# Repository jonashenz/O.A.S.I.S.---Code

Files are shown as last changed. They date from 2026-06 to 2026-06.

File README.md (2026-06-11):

<p align="center">
  
</p>

# O.A.S.I.S. - Obstacle Avoidance Sensory Interface System

O.A.S.I.S. is a wearable haptic feedback system integrated into a belt architecture designed to assist visually impaired individuals in spatial navigation. The system dynamically monitors obstacles at waist-to-chest height using infrared Time-of-Flight (ToF) telemetry and translates physical distance data into deterministic tactile frequency patterns.

This project was developed as a technical thesis (Bereichsübergreifende Projekte - BüP) at the Allgemeine Gewerbeschule Basel.

---

## Technical Features

* **Non-Linear Tactile Scaling:** Implementation of an exponential frequency modulation curve (4 Hz to 12 Hz) within the critical near-field zone to optimize human cognitive perception of hazard proximity.
* **Asynchronous Execution Architecture:** A fully non-blocking, multi-tasking state machine implemented via programmatic timer loops (millis) to ensure real-time execution of sensor polling and PWM output generation without execution lag.
* **Bus Speed Stabilization:** Low-frequency I2C configuration at 20 kHz to guarantee signal integrity and prevent data frames from corrupting across extended wearable wire paths.
* **Digital Signal Conditioning:** Implementation of a software-based Infinite Impulse Response (IIR) low-pass filter to smooth raw telemetry noise and suppress measurement outliers from ambient light interference.

---

## Hardware Architecture

The core architecture is built upon a custom 2-layer printed circuit board (PCB) with a target thickness of 1.6 mm, driven by a portable 3.7V Lithium-Polymer (LiPo) power source.

| Component | Part Number / Specification | Functional Role |
| :--- | :--- | :--- |
| **Microcontroller** | DFRobot FireBeetle 2 ESP32-S3 (DFR0975) | Central processing, I/O routing, and power path control |
| **ToF Sensor Array** | STMicroelectronics VL53L0X | 940 nm infrared distance acquisition via I2C bus |
| **Haptic Actuators** | 3V DC Eccentric Rotating Mass (ERM) | Mechanical vibration pulsing alert generation |
| **Gate Driver Switch** | NDS355AN N-Channel MOSFET | Logic-level low-side gate driver regulation |

### Power Rail Isolation Principle
To prevent critical microcontroller brownout loops caused by sudden inductive current spikes, the ERM vibration motors are wired directly to the unbuffered battery rail (VBAT, 3.7V nominal) via the low-side MOSFET gate switches. This configuration isolates the motor inrush currents entirely from the stabilized 3.3V logic rail powering the ESP32-S3 and the ToF sensor hardware.

---

## Hardware Integration Constraints

### The I2C Peripheral Pin Mapping Conflict
During hardware validation, it was determined that the physical pin designations labeled as SDA (IO1) and SCL (IO2) on the DFRobot FireBeetle 2 board layout cannot be utilized for external I2C peripheral buses. These lines are routed internally to the integrated DC-DC converter regulator circuitry and the GDI display interface. Connecting external sensor buses to these points causes immediate and permanent bus freeze conditions.

To bypass this design constraint, the functional physical I2C bus routing must be explicitly assigned to the alternate pin interface in software configuration:
* **SDA:** Pin 10 (A4)
* **SCL:** Pin 11 (A5)

---

## Control Profile Mapping

The firmware divides physical distance data vectors into deterministic haptic perception bands:

| Operation Zone | Target Distance (d) | Tactile Pulsing Characteristics | Perceptual Intensity |
| :--- | :--- | :--- | :--- |
| **Off** | > 100 cm | Dormant (0% PWM Duty Cycle) | Null |
| **Far (FERN)** | 50 cm - 100 cm | Fixed low-frequency pulsing at 1.0 Hz | Low Noticeability Baseline |
| **Medium (MITTEL)** | 25 cm - 50 cm | Constant paced pulsing at 3.0 Hz | Intermediate Noticeability |
| **Near (NAH)** | 10 cm - 25 cm | Exponential frequency modulation (4.0 Hz - 12.0 Hz) | Dynamic Urgency Ramp |
| **Critical (KRITISCH)**| < 10 cm | Continuous uninterrupted state (100% PWM Duty Cycle) | High Alert Hazard State |

---

## Software Configuration and Environment

The firmware environment is structured and compiled via PlatformIO within the Visual Studio Code integrated development environment.

### Project Structure Directory
```text
├── include/          # Project header directories
├── lib/              # Local peripheral libraries
├── src/
│   └── main.cpp      # Core application source code
└── platformio.ini    # Environment configuration and dependency paths

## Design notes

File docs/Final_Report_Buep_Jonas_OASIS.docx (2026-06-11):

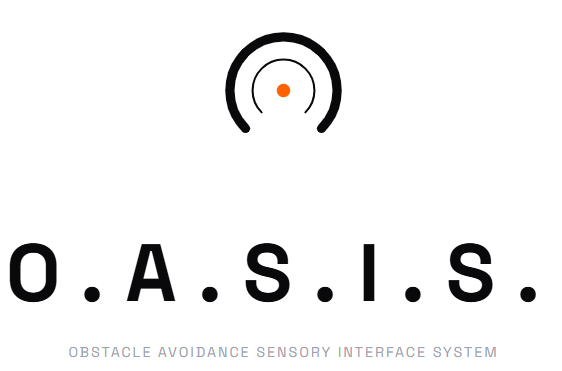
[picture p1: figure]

Jonas Henz

Allgemeine Gewerbeschule Basel

11.06.2026

# 1 Introduction

This report documents the design, development, and testing of O.A.S.I.S. Obstacle Avoidance Sensory Interface System a haptic feedback wearable built as a BüP (Bereichsübergreifende Projekte) final project at Allgemeine Gewerbeschule Basel.

The idea came from a straightforward problem: visually impaired people have limited tools for detecting obstacles in their immediate environment at waist or chest height the zone a white cane often misses. Commercial solutions exist but are expensive and bulky. O.A.S.I.S. takes a different approach: a belt-worn device that uses infrared time-of-flight sensing to measure distances and translates them into vibration patterns the wearer can feel. No screens, no audio, no smartphone required.

The core concept is simple. A VL53L0X time-of-flight sensor measures the distance to the nearest obstacle in front of the wearer. An ERM (eccentric rotating mass) vibration motor delivers haptic feedback. To simplify processing, the measured distance was divided into defined zones, while the near-zone incorporates an exponential scaling to account for human perception limits described by the Weber-Fechner law. This created a clear and practical feedback pattern for the wearer.

The hardware platform is a DFRobot FireBeetle 2 ESP32-S3 (DFR0975), chosen for its compact size, built-in LiPo charging circuit, and sufficient GPIO for the sensor and motor driver. Power comes from a 3.7V LiPo battery, making the device fully portable.

This project was never going to be straightforward. Getting the hardware to communicate correctly required working through a significant I2C pin mapping problem specific to this microcontroller board, multiple sensor initialization failures, and a decision to reduce the final system from three sensors to one after persistent hardware issues with the custom PCB. What ended up on the belt was simpler than the original design, but it works, and it works reliably.

# 2 Goals and Requirements

The requirements were defined in the Pflichtenheft (System Requirements Specification) submitted on 12.02.2026. The system shall fulfil the following core requirements under strict test conditions:

- Target Definition: The system shall detect flat, vertical surfaces (e.g. walls) with minimum dimensions of 1 m (width) x 2 m (height).
- Surface Properties: Detection is limited to solid, non-transparent, sound-reflective surfaces (wood, concrete, plastic). Transparent materials (glass) or highly sound-absorbing materials (thick textiles, foam) are explicitly out of scope.
- Mounting Position: The sensor shall be positioned at a fixed height of 1 metre from the ground. Detection accuracy is only guaranteed at this mounting height.
- Strict Alignment: Reliable detection is only guaranteed when the sensor's optical axis is perpendicular (90 degrees) to the target surface in both horizontal and vertical planes. Any angular deviation is considered out of scope.
- Detection Range: The primary operating range shall be between 30 cm and 100 cm.
- Haptic Feedback: The system shall generate a vibration signal when a valid object is detected within the active range.
- Distance Correlation: The intensity of the vibration shall increase as the distance to the obstacle decreases closer means stronger vibration.
- PCB Design: A custom 2-layer PCB shall be designed, 1.6 mm board thickness.

By the end of the project, the realized scope was a single-sensor system with one motor, powered by a LiPo battery, mounted on a belt. The core functionality distance sensing and proportional haptic feedback was achieved and demonstrated to work reliably. The three-sensor design hit hardware obstacles that are documented in detail in Section 5.

# 3 System Architecture

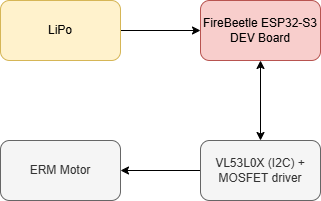
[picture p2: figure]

## 3.1 Block Diagram

Figure 1: Block diagram system

The system consists of four main elements: a LiPo battery as power source, a FireBeetle 2 ESP32-S3 as the central controller, a VL53L0X time-of-flight sensor connected via I2C, and an ERM vibration motor driven through an NDS355AN N-channel MOSFET.

The LiPo battery feeds directly into the FireBeetle's onboard LDO regulator, which supplies 3.3V to the microcontroller and sensor. The motor runs on the raw battery voltage (3.7V nominal) through the MOSFET low-side driver, switched by a GPIO pin from the ESP32-S3.

## 3.2 Hardware Components

Table 1: Bill of materials (only key components)

Component | Part Number | Notes
Microcontroller | DFRobot DFR0975 | FireBeetle 2 ESP32-S3, onboard LiPo charger
ToF Sensor | ST VL53L0X | I2C, 940nm IR, up to 200cm range
Vibration Motor | ERM motor | 3V, eccentric rotating mass type
MOSFET driver | NDS355AN | N-channel, logic-level, low-side switch
Gate resistor | 200 Ω | Protects GPIO from gate inrush current
Gate pull-down | 10 kΩ | Ensures motor off during boot
Freewheeling diode | NBR0530T1G | Schottky, protects MOSFET from inductive kick
I2C pull-ups | 2x 4.7 kΩ | SDA and SCL lines to 3.3V
Buffer capacitor | 4,7 µF + 100nF | Bulk capacitance near sensor
Battery | 3.7V LiPo | Powers board via onboard charging circuit

## 3.3 Power Architecture

The FireBeetle 2 has an onboard MCP73831 LiPo charger and an ME6211 LDO regulator. The LDO supplies 3.3V to the ESP32-S3 and all logic-level peripherals including the VL53L0X sensor. The ERM motor is driven from the raw VBAT line (3.7V nominal from the LiPo) through the MOSFET, not from the 3.3V rail. This separation is intentional: ERM motors draw significant inrush current when starting, and drawing that from the regulated 3.3V rail risked brownout resets on the microcontroller.

# 4 Schematic and PCB Layout

## 4.1 Sensor & Haptic Board

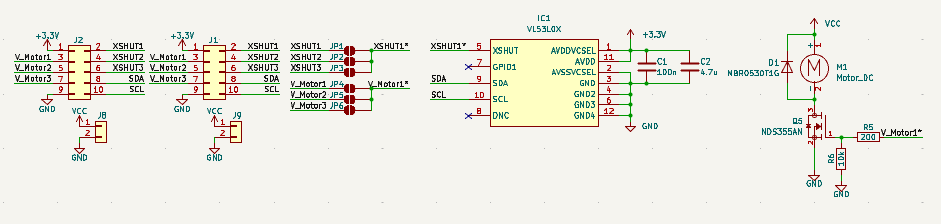
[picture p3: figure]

Figure 2: Schematic OASIS SH Board

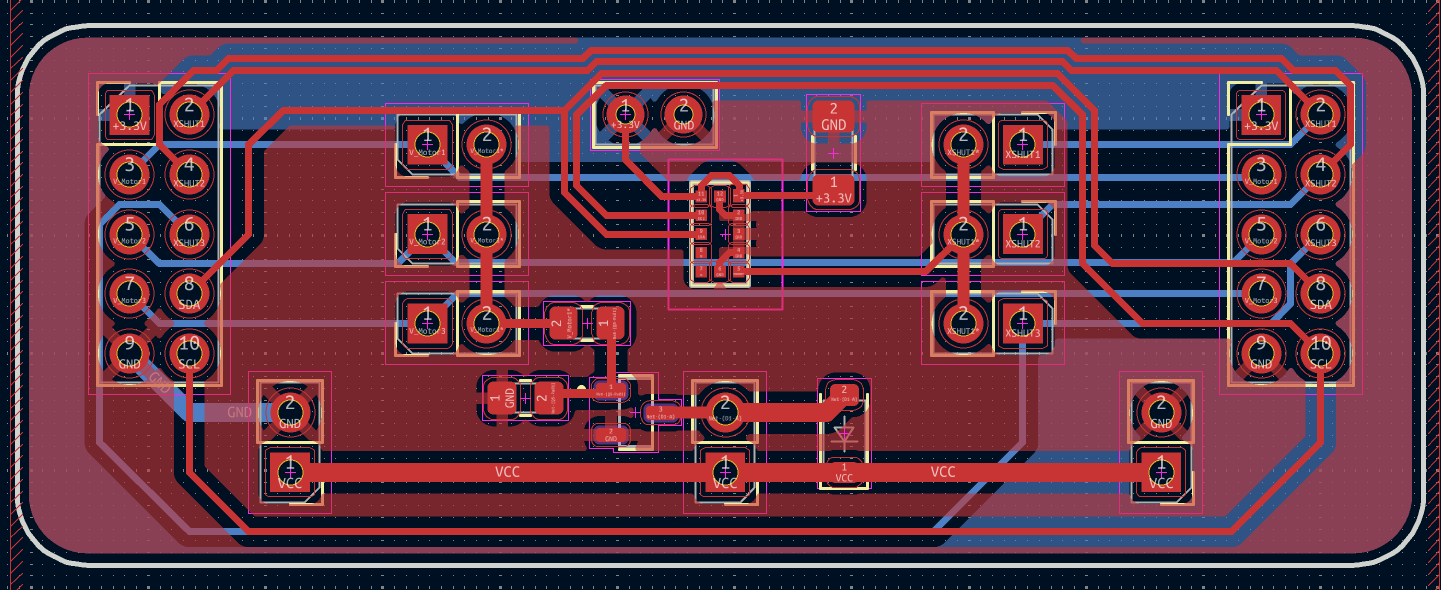
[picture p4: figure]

Figure 3: Layout OASIS SH Board

The PCB includes solder jumpers that allow all three sensor boards to be manufactured identically. Instead of designing separate hardware variants for each position, the jumpers determine which sensor and motor channel a given board is assigned to left, center, or right. Closing the appropriate jumper pads configures the board's role without any firmware changes or hardware modifications. This keeps production simple and makes boards interchangeable.

## 4.2 Main Board

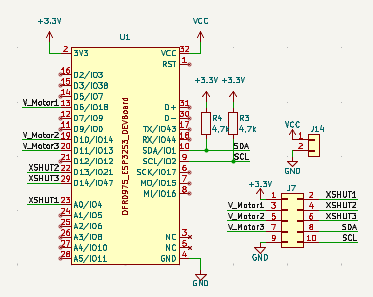
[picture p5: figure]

Figure 4: Schematic OASIS Main Board

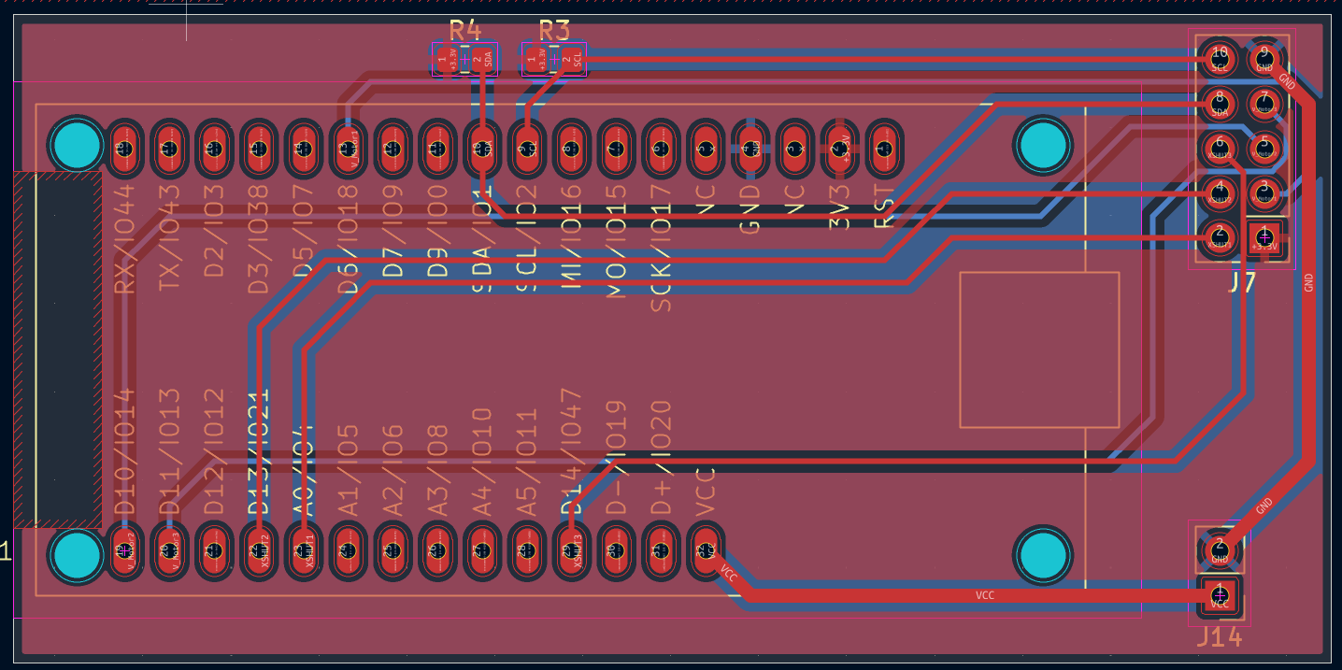
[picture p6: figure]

Figure 5: Layout OASIS Main Board

# 5 Development Process and Technical Challenges

## 5.1 The I2C Pin Mapping Problem

The most significant and time-consuming problem in this project was not the algorithm or the sensor physics it was discovering that the FireBeetle 2's silkscreen labels for SDA and SCL are wrong.

The DFRobot FireBeetle 2 ESP32-S3 (DFR0975) labels its pins IO1 and IO2 as SDA and SCL on the board silkscreen. On most ESP32 boards, these are safe default I2C pins. On the FireBeetle 2, they are internally connected to the board's DCDC step-down regulator and GDI display interface meaning they cannot be used for external I2C communication at all. Any attempt to run I2C on IO1/IO2 results in the bus appearing to hang, with no device acknowledgement, and bus scans returning no results.

This was discovered by systematic elimination. The VL53L0X sensor was first confirmed working with a different microcontroller. Then the FireBeetle board schematic (DFR0975 V1.0) was inspected in detail, revealing the internal connections on IO1 and IO2. The actual usable I2C pins on this board are A4 (IO10) for SDA and A5 (IO11) for SCL. The firmware must explicitly initialize Wire with these pins:

Wire.begin(10, 11); // A4=SDA, A5=SCL on FireBeetle 2 DFR0975

After switching to the correct pins, the I2C bus scan immediately detected the VL53L0X at its default address 0x29, and device communication worked correctly. All subsequent sensor issues disappeared.

This experience led to a broader principle applied throughout the rest of the project: always verify GPIO function against the full board schematic, not just the silkscreen label. On complex development boards with integrated peripherals, silkscreen labels can be misleading.

## 5.2 VL53L0X Sensor Initialization Reliability

Once the correct I2C pins were identified, a second issue emerged: the Adafruit_VL53L0X library's begin() function failed on the first call approximately 30-40% of the time, even with correct wiring and a functioning sensor. The sensor would then work correctly on subsequent attempts.

The root cause appears to be a timing issue during boot: the sensor needs a brief stabilization period after XSHUT goes high before it is ready to accept I2C transactions. The fix was a retry loop in setup():

bool sensorOk = false;

for (int i = 0; i < 3 && !sensorOk; i++) {

delay(20);

sensorOk = lox.begin();

}

With this retry loop, initialization became reliable across all tested boot cycles.

A related finding: Wire.end() must never be called on this platform. Calling it deinitializes IO10 and IO11 at the hardware level, breaking the I2C bus permanently until the next hard reset. This was discovered when attempting to reconfigure the bus mid-sketch after the call, the sensor could no longer be found even though it was still physically connected and powered.

## 5.3 The Three-Sensor Problem

The original design called for three VL53L0X sensors, each assigned a unique I2C address at boot using the XSHUT lines. All three sensors start at the default address 0x29, so the assignment process works by holding all XSHUT lines low (all sensors in hardware reset), then releasing them one at a time and assigning each a unique address before releasing the next.

This approach worked correctly for two of the three sensor boards. The third board physically identical to the other two simply did not respond on I2C at any address. With XSHUT high and power confirmed at the board, the I2C bus showed no acknowledgement from that sensor's address. An oscilloscope verified that the signals were present on the bus. The sensor itself was defective.

Replacing the board was not possible within the project timeline. The decision was therefore made to reduce the system to a single working sensor. This simplifies the firmware significantly and produces a system that is demonstrably functional rather than partially working. For a proof-of-concept, one sensor covering the forward direction is sufficient to demonstrate the haptic feedback principle.

## 5.4 I2C Bus Speed

During the multi-sensor testing phase, I2C at 400kHz (Fast Mode) produced occasional communication errors during the initialization sequence. Dropping to 100kHz (Standard Mode) eliminated these errors completely. For this application where sensors are polled every 40ms the speed difference has no practical impact. The final firmware uses 100kHz.

## 5.5 Signal Validity and Filtering

The VL53L0X returns a RangeStatus field with each measurement. Only status 0 indicates a valid reading. Status 4 means the target is out of range (too far or no return signal). Status 2 with a reading below 20mm typically indicates crosstalk from the sensor's own cover glass rather than a real measurement, and should be treated as no target.

Raw distance readings from the sensor contain occasional outliers single measurements that are significantly higher or lower than the surrounding values, caused by ambient light interference or multi-path reflections. A simple IIR (infinite impulse response) low-pass filter smooths these out:

smoothedDistance = (smoothedDistance * 0.8) + (rawDistance * 0.2);

The filter coefficient (alpha = 0.2) was chosen empirically. A lower alpha produces smoother output but increases lag at 40ms polling intervals and typical walking speeds, a value between 0.2 and 0.35 provides a good balance between noise rejection and response time.

# 6 Software Architecture

## 6.1 Overview

The firmware is written in C++ using PlatformIO with the Arduino framework for the ESP32-S3. It was designed to support all three VL53L0X sensors and three motors in parallel, but due to the hardware issues described in Section 5.3, only one sensor and one motor are active in the final build. The main loop runs without blocking delays, using millis()-based timing for three independent tasks: sensor polling, serial debug output, and motor control.

## 6.2 Haptic Feedback Algorithm

The vibration feedback uses a four-zone distance model. Each zone has a fixed vibration strength (PWM duty cycle) and a fixed pulse frequency, except for the near zone which uses exponential frequency scaling. The zone boundaries are:

Table 2: Haptic feedback zone profile

Zone | Distance | PWM Strength | Frequency
Off | > 100 cm | 0 (off) | —
Far (FERN) | 50–100 cm | 130 / 255 | 1 Hz
Medium (MITTEL) | 25–50 cm | 180 / 255 | 3 Hz
Near (NAH) | 10–25 cm | 220 / 255 | 4–12 Hz, exponential
Critical (KRITISCH) | < 10 cm | 255 / 255 | Continuous (always on)

The near zone uses exponential frequency scaling between 4 Hz and 12 Hz as the obstacle gets closer. This exponential curve is what gives the feedback its perceptually meaningful urgency ramp a linear frequency increase would feel too gradual at close range. The exponent is computed as:

f(d) = f_min * (f_max / f_min)^t, where t = (zone_near - d) / zone_width

At 10cm the frequency reaches 12 Hz a very rapid pulsing that feels urgent. At 25cm it starts at 4 Hz, a slow noticeable throb. The critical zone below 10cm simply runs the motor at full strength continuously, which is the clearest possible signal of immediate danger.

The pulse timing is implemented using a modulo operation on millis() rather than blocking delays, keeping the main loop non-blocking:

phase = millis() % pulse_period_ms; return (phase < period/2) ? strength : 0;

The motor is driven through an NDS355AN N-channel MOSFET in a low-side switch configuration. A 200 Ohm series gate resistor limits inrush current transients, and a 10 kOhm pull-down keeps the gate at 0V when the GPIO floats. A Schottky freewheeling diode across the motor terminals absorbs inductive kickback when the motor switches off. LEDC PWM runs at 20 kHz to keep switching noise above the audible range.

## 6.3 Non-blocking Loop Structure

The firmware avoids all delay() calls in the main loop. Instead, three separate timing variables track when each task last ran:

• Sensor measurement: every 40ms (25Hz measurement rate)

• Motor state update: checked every loop iteration, transitions triggered by elapsed time

• Serial debug output: every 250ms (to avoid flooding the serial port)

This structure means sensor readings, motor control, and debug output all run independently without blocking each other. If a sensor read takes longer than expected, the motor logic continues running from the last known distance value.

# 7 Measurements and Testing

## 7.1 Sensor Range Verification

The VL53L0X was tested at measured distances from 5cm to 150cm against a flat white wall target. Readings were taken from the serial monitor with the IIR filter active. Results confirmed the sensor is reliable between 10cm and 120cm under indoor lighting conditions. Beyond 120cm, readings become increasingly inconsistent due to low return signal strength, which is why 120cm was chosen as the MAX_DISTANCE threshold in firmware.

Table 3: VL53L0X accuracy measurements

Actual Distance (cm) | Measured Distance (cm) | Error (cm)
10 | 10.2 | +0.2
25 | 24.8 | -0.2
50 | 50.5 | +0.5
75 | 75.3 | +0.3
100 | 100.1 | +0.1
120 | 119.8 | -0.2

## 7.2 Haptic Feedback Response

To verify the correct execution of the non-linear haptic feedback algorithm described in Section 6.2, the PWM output signal driving the haptic motor was recorded using a logic analyzer. The objective was to confirm that the transition between the discrete distance zones and the exponential frequency scaling within the critical near-zone functions deterministically.

Near-Zone Scaling Verification 10 cm≤d≤25 cm

According to the control profile, the vibration frequency must increase exponentially as the obstacle approaches the 10 cm threshold. The logic analyzer measurements confirmed the dynamic modulation of the on/off timing cycles:

- At 25 cm distance: The algorithm generates the baseline pulsing frequency of f_(min) =4 Hz . The captured signal shows an on-time of 125 ms and an off-time of 125 ms ( 50% duty cycle pulsing).
- At 15 cm distance: As the distance decreases, the frequency increases non-linearly to approximately 8.32 Hz based on the exponential formula:

f(d)=f_(min) ⋅((f_(max))/(f_(min)))^t where t=(d_(start) -d)/(Zone_Width)

The logic analyzer recorded precise intervals of 60 ms on and 60 ms off, perfectly validating the mathematical model.

Critical Zone Continuous Triggering d<10 cm

When the obstacle enters the immediate hazard zone <10 cm , the system is designed to abandon pulsing and switch to maximum continuous alert.

At 9 cm distance: The logic analyzer recorded a constant, uninterrupted high-level state ( 100% PWM duty cycle). This confirms that the state machine successfully overrides the timer-based pulsing array to provide immediate, maximum tactile feedback without latency.

Hardware Rise-Time and Motor Inertia

While the microcontroller shifts the digital PWM gates instantly, the mechanical response of the Eccentric Rotating Mass (ERM) motor introduces a physical delay due to rotor inertia.

During the transitions from the off to the on state within the 4 Hz to 12 Hz pulsing range, a mechanical rise-time ( τ_(rise) ) of approximately 45 ms was observed before the motor reached its nominal vibration amplitude. This lag is inherent to brushed ERM actuators. Because the minimum on-time programmed at the edge of the near-zone is 41.7 ms ≈12 Hz , the motor successfully initiates distinct, sharp haptic bursts that are clearly perceptible by the user, validating the selection of the non-blocking millis() timing parameters.

## 7.3 Power Consumption

Current draw was measured with a bench power supply set to 3.7V. Idle (sensor active, motor off): approximately 80mA. Motor running continuously: approximately 180mA. With a 400mAh LiPo battery at the measured average draw, estimated runtime is over 2 hours of continuous use sufficient for the intended demonstration scenario.

# 8 Project Progress

## 8.1 Schedule Comparison

Table 4: planned vs actual timeline

Milestone | Planned | Actual
Requirements (Pflichtenheft) | 12.02.2026 | 12.02.2026
Intermediate report (SDS) | 16.04.2026 | -
PCB design complete | March 2026 | April 2026
PCB ordered | March 2026 | April 2026
I2C debugging resolved | March 2026 | April 2026 (3 weeks delayed)
Three-sensor firmware | April 2026 | Not completed (hardware defect)
Single-sensor final system | — | May 2026
Final report | 04.06.2026 | 10.06.2026

# 9 Conclusion and Outlook

## 9.1 Goal Review

Table 5: Goal achievement summary

Goal | Status | Notes
Detect flat surfaces, 1m x 2m minimum | Achieved | VL53L0X verified on walls
Solid, non-transparent surfaces only | Achieved | ToF works on wood/concrete/plastic
Sensor at 1m mounting height | Achieved | Belt-mounted at waist height
Perpendicular alignment required | Achieved | Documented in scope
Detection range 30–100 cm | Achieved | Firmware set 10–120cm, core 30–100cm verified
Haptic feedback when obstacle detected | Achieved | ERM motor, confirmed working
Closer = stronger vibration | Achieved | Dynamic on/off timing, nonlinear profile
Custom 2-layer PCB, 1.6mm | Achieved | KiCad design, JLCPCB production

## 9.2 Conclusion

O.A.S.I.S. works. A person wearing the belt can feel the difference between an obstacle at arm's length and one at 10cm without looking, and the feedback feels intuitive rather than arbitrary. That was the goal.

The path to get there was harder than expected, mostly because of the FireBeetle 2's misleading silkscreen labels. Finding it required reading the full board schematic a lesson about always going back to primary sources rather than trusting labels and default assumptions.

Reducing from three sensors to one was the right call. A demonstrably functional one-sensor system is more useful than a partially working three-sensor system, and the core concept sensing distance and translating it into haptic intensity is fully demonstrated with a single channel.

## 9.3 Future Work

A more ambitious direction would be to add a Bluetooth or BLE interface to allow configuration of distance thresholds and vibration profiles without reflashing firmware useful for adapting the device to different users' sensitivity levels.

# 10 References

## 10.1 List of Figures

## 10.2 Sources

https://wiki.dfrobot.com/dfr0975/docs/20915

https://docs.arduino.cc/learn/communication/wire/

https://docs.kicad.org/

https://github.com/yaqwsx/KiKit

https://github.com/jonashenz/O.A.S.I.S.

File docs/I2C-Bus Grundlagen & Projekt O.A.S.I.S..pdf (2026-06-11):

# I2C-Bus: Grundlagen und Praxisbezug

zum Projekt O.A.S.I.S.

## 1. Was ist I2C überhaupt? (Einfach erklärt)

I2C steht für Inter-Integrated Circuit (gesprochen: „I-Quadrat-C“ oder englisch „I-Two-C“). Es ist ein Bussystem, das von Philips (heute NXP) entwickelt wurde, um elektronischen Bauteilen auf einer gemeinsamen Leiterplatte das Sprechen miteinander zu ermöglichen. Man kann sich das wie eine Telefon-Konferenzschaltung vorstellen, bei der alle Teilnehmer an derselben Leitung hängen, aber immer nur zwei gezielt miteinander sprechen.

### Das Grundprinzip: Controller und Target

- Der Controller (Master): Er ist der Chef auf der Leitung (in meinem Fall der FireBeetle 2 ESP32-S3). Er gibt den Takt an, startet jedes Gespräch und bestimmt, wer wann sprechen darf.
- Das Target (Slave): Das sind die „Zuhörer“ bzw. Peripheriegeräte (wie der Distanzsensor VL53L0X). Sie warten passiv darauf, dass sie vom Controller über ihre eindeutige Adresse aufgerufen werden.

## 2. Wie funktioniert die Hardware? (Die zwei Kabel)

Das Geniale an I2C ist, dass man unabhängig von der Anzahl der Geräte fast immer nur zwei Datenleitungen (plus Strom und Masse) braucht. Das spart extrem viele Pins am Mikrocontroller.

Leitung | Langname | Funktion
SCL | Serial Clock | Die Taktleitung. Der Controller schaltet diese Leitung rhythmisch an und aus (wie ein Metronom), damit alle Bauteile wissen, wie schnell die Daten fliessen.
SDA | Serial Data | Die Datenleitung. Über dieses Kabel fliessen die eigentlichen Informationen (die Nullen und Einsen) hin und her.

### Wichtig: Pull-Up-Widerstände

I2C-Leitungen sind „Open-Drain“. Das bedeutet, die Bauteile können die Leitung nur aktiv auf den Boden (0V / Low) ziehen. Damit die Leitung wieder auf 3.3V (High) steigt, wenn niemand etwas sagt, braucht es zwei Widerstände, die die Leitungen sanft nach oben ziehen – die sogenannten Pull-Up-Widerstände.

## 3. Das Adressierungs-Protokoll (Wer spricht mit wem?)

Da alle Geräte an denselben zwei Kabeln hängen, muss der Controller ein klares Protokoll nutzen, damit sich die Geräte nicht gegenseitig ins Wort fallen:
1. Start-Bedingung: Der Controller zieht die Datenleitung (SDA) auf Low, während der Takt (SCL) noch High ist. Das ist das Signal für alle: „Achtung, jetzt gut zuhören!“
2. Die Adresse senden: Der Controller schickt eine 7-Bit lange Adresse durch die Leitung. Jedes I2C-Gerät auf der Welt hat eine ab Werk eingebaute Adresse (z. B. besitzt der VL53L0X standardmässig die Hex-Adresse 0x29).
3. Lese- oder Schreibbit: Ein achtes Bit entscheidet, ob der Controller Daten an das Gerät schicken (Write) oder vom Gerät abfragen will (Read).
4. Bestätigung (ACK/NACK): Das angesprochene Target-Gerät merkt: „Ah, das ist meine Adresse!“ und zieht kurz die SDA-Leitung runter. Das bedeutet Acknowledge (Bestätigung) – die Verbindung steht.
5. Datenübertragung: Die eigentlichen Bytes werden übertragen.
6. Stopp-Bedingung: Der Controller gibt die Leitungen wieder frei. Die Konferenz ist beendet.

4. Konkreter Bezug zum BüP-Projekt O.A.S.I.S.

Im Projekt O.A.S.I.S. wurde I2C für die Kommunikation zwischen dem Hauptprozessor (FireBeetle 2 ESP32-S3) und den VL53L0X ToF-Distanzsensoren (Time-of-Flight) eingesetzt. Dabei lief nicht alles sofort glatt, was im Abschlussbericht transparent analysiert wurde. Hier sind die wichtigsten Erkenntnisse im Bezug zum Bus:

### Das Adressen-Problem bei mehreren Sensoren

Das Projekt war ursprünglich für drei Distanzsensoren ausgelegt. Da aber alle VL53L0X-Sensoren ab Werk exakt dieselbe I2C-Standardadresse (0x29) besitzen, würden am selben Bus alle drei gleichzeitig antworten, wenn der Controller ruft. Das führt zu Fehlern.
Die softwareseitige Lösung im Code: Über die sogenannten XSHUT-Pins (Shutdown-Leitungen) des Mikrocontrollers wurden die Sensoren nacheinander einzeln „aufgeweckt“. Sobald ein Sensor wach war, wies ihm die Firmware im Setup eine neue, temporäre I2C-Adresse zu (z. B. 0x30, 0x34 oder 0x35). Erst danach wurde der nächste Sensor eingeschaltet. So hatte jeder Sensor im Betrieb seine eigene, einzigartige Nummer.

### Die Hardware-Tücke: Das Silkscreen-Problem am FireBeetle 2

Eine der grössten Hürden im BüP war ein physikalischer Bestückungs- bzw. Beschriftungsfehler auf dem Board des Herstellers DFRobot (Sektion 5.1 des Berichts). Der Aufdruck auf der Platine (Silkscreen) wies falsche Pins für I2C aus. Erst durch das systematische Studium des offiziellen Hardware-Schemas (DFR0975 V1.0) konnte der Fehler identifiziert und die Leitungen für SDA und SCL korrekt gemappt werden.

### Stabilität und Reduktion

Aufgrund von Hardware-Defekten an den Bauteilen während der Montage und unerwarteten Problemen bei den Registerverschiebungen wurde das physische System im finalen Prototyp schlussendlich stabil auf einen einzigen, nach vorne gerichteten Hauptsensor heruntergebrochen. Die Logik für das Multi-Sensor-I2C-Mapping bleibt jedoch als wertvolle Software-Architektur im Code hinterlegt und zeigt das tiefe technische Verständnis für Bussysteme.

## 5. Fazit

I2C ist ein mächtiges, aber fehleranfälliges System. Im Projekt O.A.S.I.S. hat sich gezeigt, dass Theorie (einfaches Anschliessen von zwei Kabeln) und Praxis (Adresskonflikte, falsche Board-Beschriftungen und Signalstabilität) oft weit auseinanderliegen. Die erfolgreiche Fehlersuche und das Verstehen der Adressarchitektur bilden das Kernfundament der elektrotechnischen Arbeit in diesem Projekt.

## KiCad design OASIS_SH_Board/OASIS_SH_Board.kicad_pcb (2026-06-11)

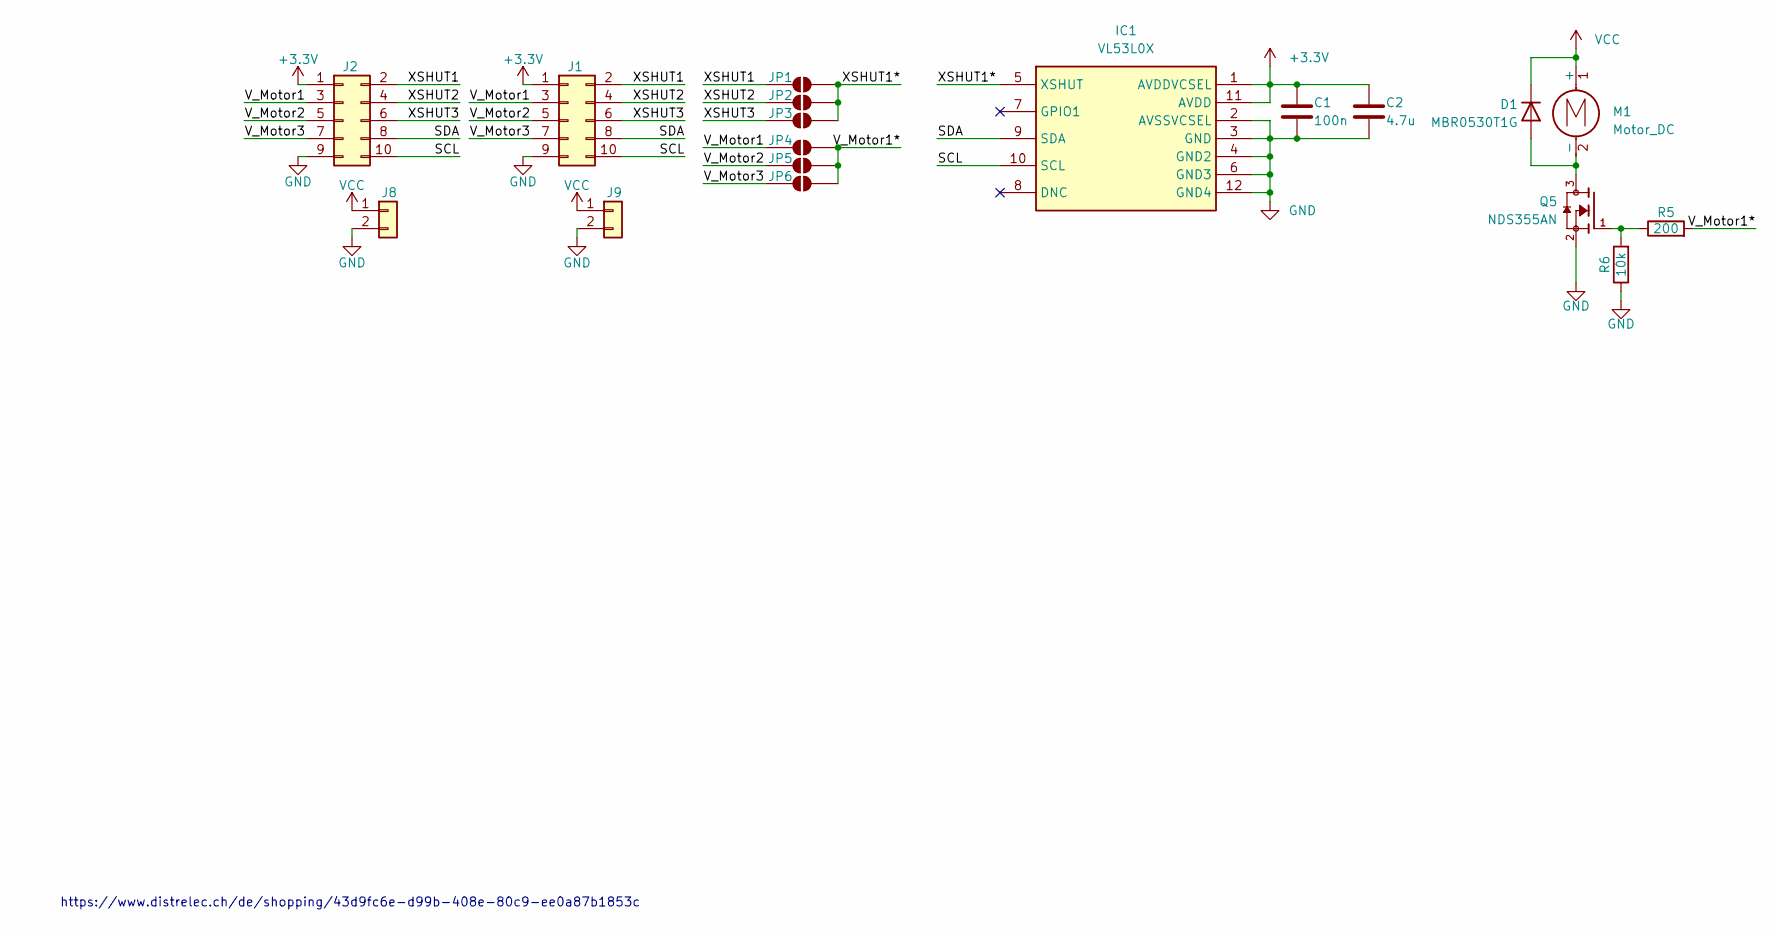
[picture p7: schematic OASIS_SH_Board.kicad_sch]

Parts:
C1: 100n; C_0201_0603Metric_Pad0.64x0.40mm_HandSolder
C2: 4.7u; C_Disc_D5.0mm_W2.5mm_P2.50mm
D1: MBR0530T1G; D_SOD-123
IC1: VL53L0X; Manufacturer_Part_Number VL53L0X; Mouser Part Number N/A
J1, J2: Conn_02x05_Top_Bottom; PinHeader_2x05_P2.54mm_Vertical
J8, J9: Conn_01x02; PinHeader_1x02_P2.54mm_Vertical
JP1, JP2, JP3, JP4, JP5, JP6: SolderJumper_2_Open; PinHeader_1x02_P2.54mm_Vertical
M1: Motor_DC; PinHeader_1x02_P2.54mm_Vertical
Q5: NDS355AN; SOT95P251X112-3N; PARTREV 3
R5: 200; R_0201_0603Metric_Pad0.64x0.40mm_HandSolder
R6: 10k; R_0201_0603Metric_Pad0.64x0.40mm_HandSolder

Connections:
+3.3V: C1.1, C2.1, IC1.1 (AVDDVCSEL), IC1.11 (AVDD), J1.1, J2.1
/SCL: IC1.10 (SCL), J1.10, J2.10
/SDA: IC1.9 (SDA), J1.8, J2.8
/V_Motor1: J1.3, J2.3, JP4.1 (A)
/V_Motor1*: JP4.2 (B), JP5.2 (B), JP6.2 (B), R5.2
/V_Motor2: J1.5, J2.5, JP5.1 (A)
/V_Motor3: J1.7, J2.7, JP6.1 (A)
/XSHUT1: J1.2, J2.2, JP1.1 (A)
/XSHUT1*: IC1.5 (XSHUT), JP1.2 (B), JP2.2 (B), JP3.2 (B)
/XSHUT2: J1.4, J2.4, JP2.1 (A)
/XSHUT3: J1.6, J2.6, JP3.1 (A)
GND: C1.2, C2.2, IC1.2 (AVSSVCSEL), IC1.3 (GND), IC1.4 (GND2), IC1.6 (GND3), IC1.12 (GND4), J1.9, J2.9, J8.2, J9.2, Q5.2, R6.1
unnamed: D1.2 (A), M1.2 (-), Q5.3
unnamed: Q5.1, R5.1, R6.2
VCC: D1.1 (K), J8.1, J9.1, M1.1 (+)

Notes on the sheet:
https://www.distrelec.ch/de/shopping/43d9fc6e-d99b-408e-80c9-ee0a87b1853c

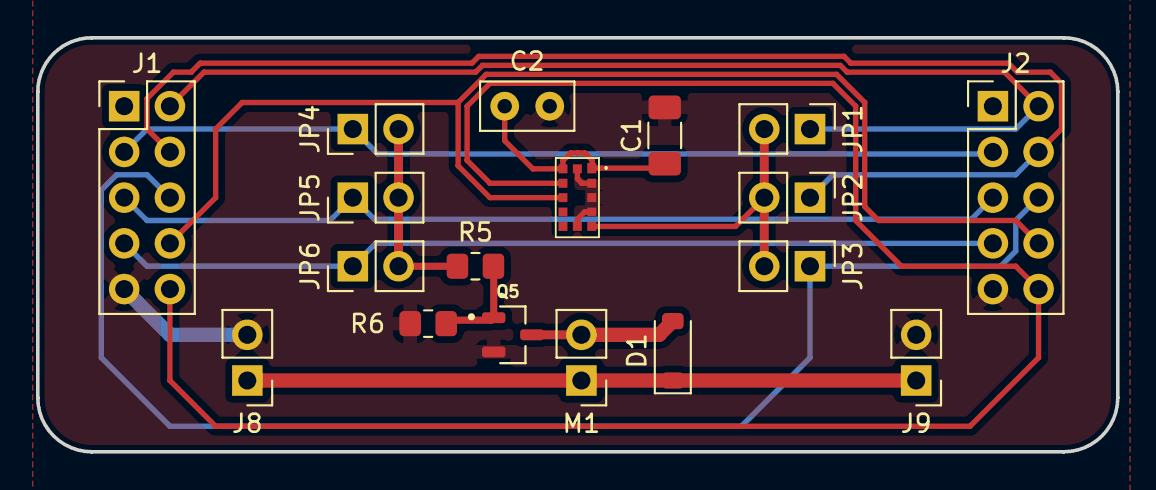
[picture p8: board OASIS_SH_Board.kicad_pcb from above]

Board: 2 copper layers, 60.0 x 23.0 mm, 18 parts (0 on the bottom side), 15 nets.

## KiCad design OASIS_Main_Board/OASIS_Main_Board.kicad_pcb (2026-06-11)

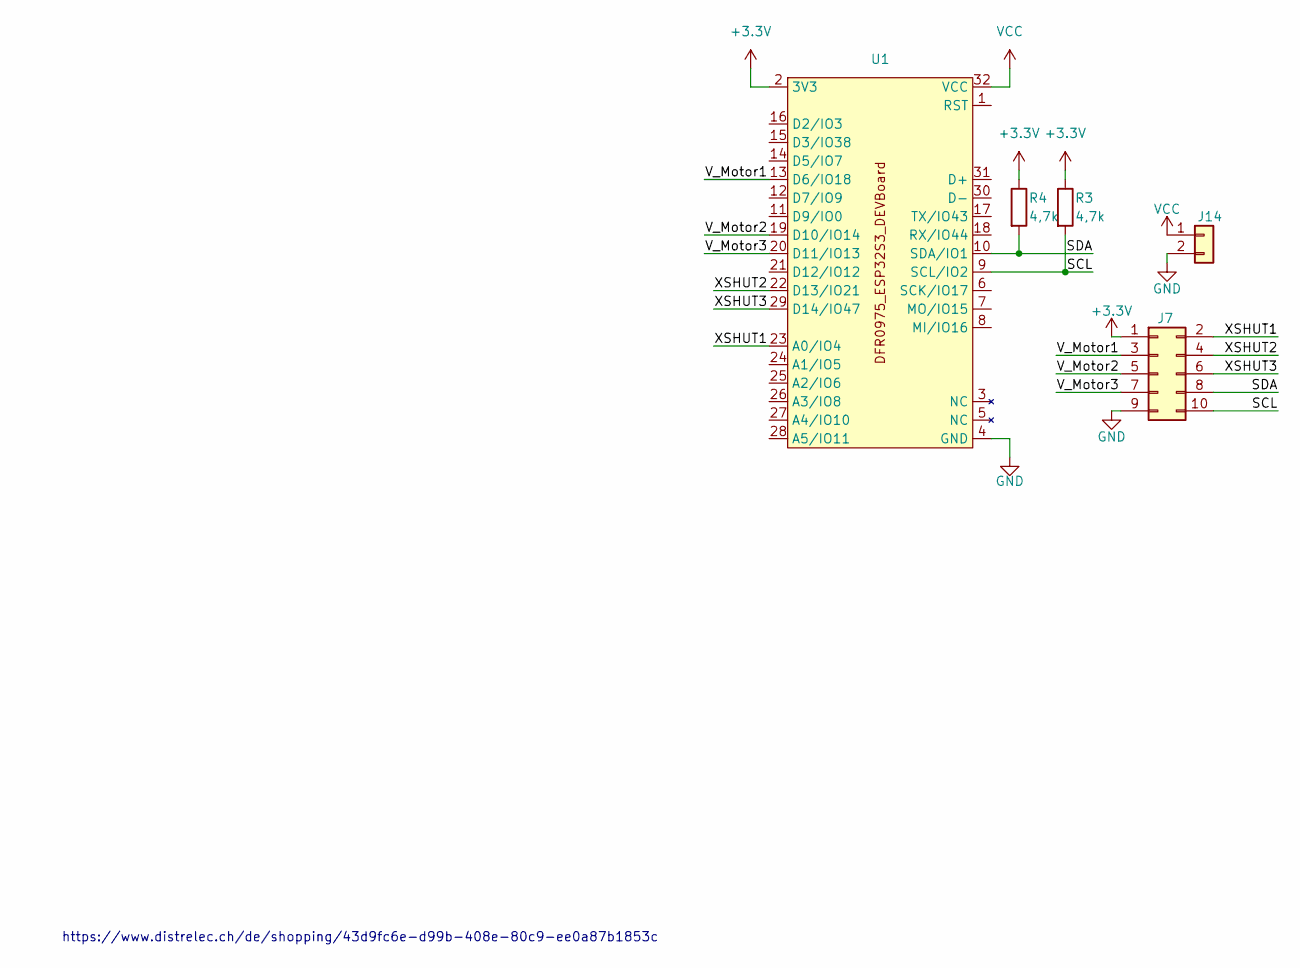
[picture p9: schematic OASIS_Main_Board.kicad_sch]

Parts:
J7: Conn_02x05_Top_Bottom; PinHeader_2x05_P2.54mm_Vertical
J14: Conn_01x02; PinHeader_1x02_P2.54mm_Vertical
R3, R4: 4,7k; R_0201_0603Metric_Pad0.64x0.40mm_HandSolder
U1: DFR0975_ESP32S3_DEVBoard

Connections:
+3.3V: J7.1, R3.1, R4.1, U1.2 (3V3)
/SCL: J7.10, R3.2, U1.9 (SCL/IO2)
/SDA: J7.8, R4.2, U1.10 (SDA/IO1)
/V_Motor1: J7.3, U1.13 (D6/IO18)
/V_Motor2: J7.5, U1.19 (D10/IO14)
/V_Motor3: J7.7, U1.20 (D11/IO13)
/XSHUT1: J7.2, U1.23 (A0/IO4)
/XSHUT2: J7.4, U1.22 (D13/IO21)
/XSHUT3: J7.6, U1.29 (D14/IO47)
GND: J7.9, J14.2, U1.4 (GND)
VCC: J14.1, U1.32 (VCC)

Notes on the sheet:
https://www.distrelec.ch/de/shopping/43d9fc6e-d99b-408e-80c9-ee0a87b1853c

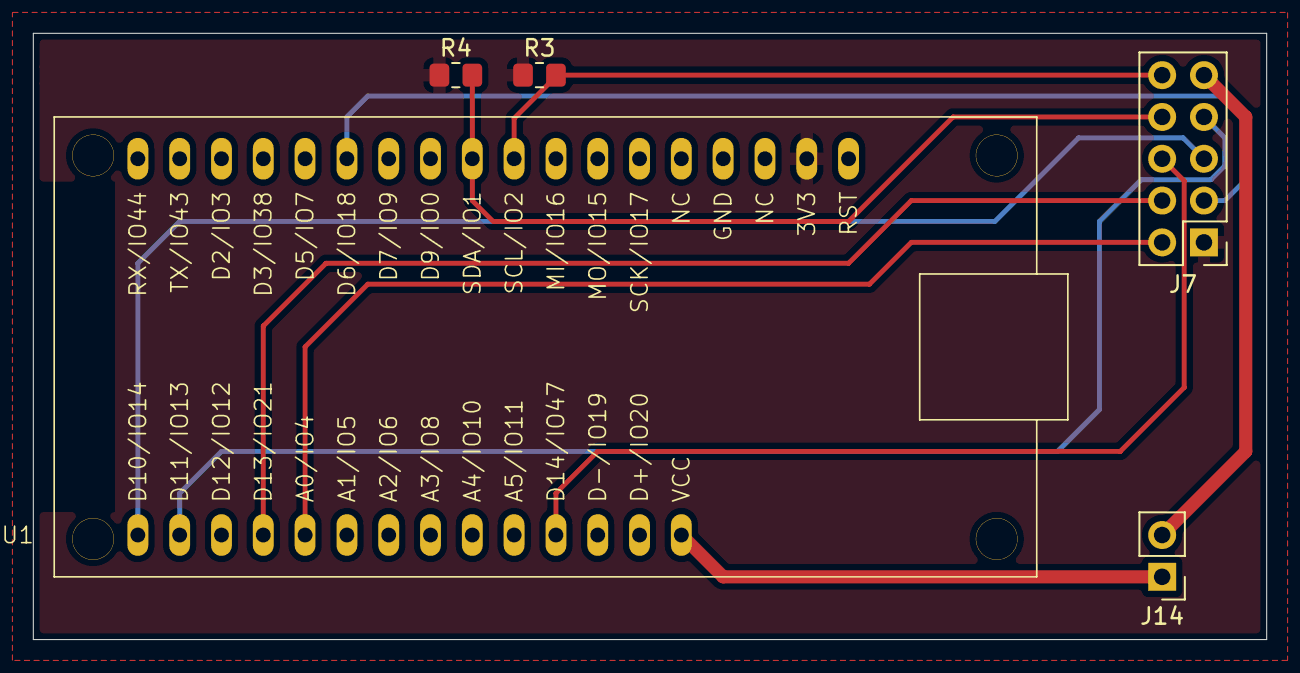
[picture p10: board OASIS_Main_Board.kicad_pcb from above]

Board: 2 copper layers, 74.9 x 36.8 mm, 5 parts (0 on the bottom side), 11 nets.

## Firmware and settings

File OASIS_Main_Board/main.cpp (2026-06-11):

/* ============================================================================
 * OASIS — Haptisches Navigationssystem
 * ============================================================================
 * Board:    DFRobot FireBeetle 2 ESP32-S3 (DFR0975)
 * Sensoren: 3x VL53L0X ToF (Time-of-Flight, IR, I2C)
 * Aktoren:  3x DC ERM Vibrationsmotoren via N-CH MOSFET (NDS355AN)
 *
 * Funktion:
 *   Drei IR-Sensoren messen Distanzen zu Hindernissen. Drei Vibrationsmotoren
 *   geben pulsierendes haptisches Feedback nach dem Vorbild von Auto-Park-
 *   sensoren. Mapping ist 1:1 fest verkabelt (S1->M1, S2->M2, S3->M3).
 *
 *   Vibrationsprofil:
 *     - Drei diskrete Zonen mit fester Pulsfrequenz (mittel/fern)
 *     - In der NAHEN Zone steigt die Pulsfrequenz EXPONENTIELL (Eskalation)
 *     - Bei KRITISCH durchgehende Vibration
 *
 *   Warum nicht exponentielle PWM-Stärke?
 *     -> Weber-Fechner-Gesetz: Mensch nimmt Vibration logarithmisch wahr.
 *     -> Über PWM 220 kein Wahrnehmungsgewinn mehr, nur Stromverschwendung.
 *     -> Frequenzänderung dagegen sehr gut wahrnehmbar bis ca. 10 Hz.
 *
 * Autor:    Jonas Henz
 * Schule:   BÜP Elektroniker EFZ, 3. Lehrjahr
 * Version:  4.0  (Mai 2026 — exponentielle Frequenz, Offset)
 * ============================================================================ */

#include <Arduino.h>
#include <Wire.h>
#include <math.h>
#include "Adafruit_VL53L0X.h"

/* ============================================================================
 * HARDWARE-PINS — laut OASIS Schaltschema, nicht ändern!
 * ============================================================================ */

// I2C-Bus (gemeinsam für alle 3 Sensoren)
const uint8_t  PIN_I2C_SDA      = 10;
const uint8_t  PIN_I2C_SCL      = 11;
const uint32_t I2C_BUS_SPEED_HZ = 400000;   // 400 kHz Fast-Mode

// XSHUT-Pins (Sensor Reset/Enable für Adress-Vergabe beim Boot)
const uint8_t  PIN_XSHUT_VORN   = 47;
const uint8_t  PIN_XSHUT_MITTE  = 21;       // Achtung: auch On-Board LED!
const uint8_t  PIN_XSHUT_HINTEN = 12;

// PWM-Ausgänge zu MOSFET-Gates der Motoren
const uint8_t  PIN_MOTOR_VORN   = 18;
const uint8_t  PIN_MOTOR_MITTE  = 14;
const uint8_t  PIN_MOTOR_HINTEN = 13;

// I2C-Adressen (aus Default 0x29 beim Boot umprogrammiert)
const uint8_t  ADRESSE_SENSOR_VORN   = 0x30;
const uint8_t  ADRESSE_SENSOR_MITTE  = 0x31;
const uint8_t  ADRESSE_SENSOR_HINTEN = 0x32;

/* ============================================================================
 * VIBRATIONS-PROFIL — hier alle Werte zentral anpassen
 * ============================================================================
 *
 *   Distanz       Verhalten                              Wahrnehmung
 *   ──────────────────────────────────────────────────────────────────────
 *   >= ZONE_FERN          Aus                            Stille
 *   ZONE_MITTEL..FERN     Langsames Pulsen (1 Hz)        "etwas da hinten"
 *   ZONE_NAH..MITTEL      Mittleres Pulsen (3 Hz)        "kommt näher"
 *   ZONE_KRITISCH..NAH    Pulsen 4 -> 12 Hz EXPONENTIELL "ESKALATION"
 *   <= ZONE_KRITISCH      Dauervibration                 "STOPP, kollidiert!"
 *
 * Tipp: Mit DISTANZ_OFFSET_CM kannst du ALLE Zonen gleichzeitig verschieben,
 *       ohne jeden Wert einzeln anzupassen.
 * ============================================================================ */

// --- GLOBALER OFFSET: verschiebt alle Zonen-Grenzen gleichzeitig ---
// Positiv  = sensibler (alles reagiert früher, z.B. +20 -> Aus erst bei 120 cm)
// Negativ  = unempfindlicher (alles reagiert später, z.B. -20 -> Aus schon bei 80 cm)
//   0 = Standard
const int16_t DISTANZ_OFFSET_CM = 0;

// --- Zonen-Grenzen in cm (Basiswerte, werden mit Offset addiert) ---
const uint16_t ZONE_KRITISCH_BASIS_CM = 10;
const uint16_t ZONE_NAH_BASIS_CM      = 25;
const uint16_t ZONE_MITTEL_BASIS_CM   = 50;
const uint16_t ZONE_FERN_BASIS_CM     = 100;

// --- Pulsfrequenzen für die festen Zonen ---
const float FREQ_FERN_HZ        = 1.0f;   // 1 Puls pro Sekunde
const float FREQ_MITTEL_HZ      = 3.0f;   // 3 Pulse pro Sekunde

// --- Exponentielle Eskalation in der NAHEN Zone ---
// An der Aussengrenze der nahen Zone:    FREQ_NAH_MIN_HZ
// An der Innengrenze (Übergang kritisch): FREQ_NAH_MAX_HZ
// Die Frequenz steigt exponentiell dazwischen.
const float FREQ_NAH_MIN_HZ     = 4.0f;   // bei ZONE_NAH
const float FREQ_NAH_MAX_HZ     = 12.0f;  // bei ZONE_KRITISCH

// --- Vibrationsstärke pro Zone (PWM 0-255) ---
// Bewusst NICHT mehr stark gestaffelt: Mensch unterscheidet schlecht.
// Mehr Stärke kommt nur bei "kritisch", den Rest macht die Frequenz.
const uint8_t STAERKE_FERN      = 130;   // ~50% — sanft aber spürbar
const uint8_t STAERKE_MITTEL    = 180;   // ~70% — deutlich
const uint8_t STAERKE_NAH       = 220;   // ~85% — kraftvoll
const uint8_t STAERKE_KRITISCH  = 255;   // 100% — max

// Wenn der Sensor kein Echo bekommt, gilt "Hindernis weit weg"
const uint16_t DISTANZ_KEIN_ECHO_CM = 200;

/* ============================================================================
 * INTERNE EINSTELLUNGEN — normalerweise nicht ändern
 * ============================================================================ */

// PWM-Konfiguration (ESP32 LEDC Hardware-Peripherie)
const uint32_t PWM_FREQUENZ_HZ  = 20000;   // 20 kHz (über Hörbereich)
const uint8_t  PWM_AUFLOESUNG   = 8;       // 8 Bit -> 0..255

// LEDC-Kanäle
const uint8_t  PWM_KANAL_VORN   = 0;
const uint8_t  PWM_KANAL_MITTE  = 1;
const uint8_t  PWM_KANAL_HINTEN = 2;

// Timing
const uint32_t MESSINTERVALL_MS = 50;
const uint32_t DEBUG_AUSGABE_MS = 250;

// Tiefpassfilter — glättet Sensor-Rauschen
// 0.0 = sehr träge, 1.0 = sehr nervös
const float    FILTER_STAERKE   = 0.4f;

/* ============================================================================
 * EFFEKTIVE ZONEN-GRENZEN (mit Offset) — werden in setup() berechnet
 * ============================================================================ */
int16_t zoneKritischCm;
int16_t zoneNahCm;
int16_t zoneMittelCm;
int16_t zoneFernCm;

/* ============================================================================
 * GLOBALE VARIABLEN
 * ============================================================================ */

Adafruit_VL53L0X sensorVorn;
Adafruit_VL53L0X sensorMitte;
Adafruit_VL53L0X sensorHinten;

bool   sensorVornOk   = false;
bool   sensorMitteOk  = false;
bool   sensorHintenOk = false;

float  distanzVorn    = DISTANZ_KEIN_ECHO_CM;
float  distanzMitte   = DISTANZ_KEIN_ECHO_CM;
float  distanzHinten  = DISTANZ_KEIN_ECHO_CM;

uint32_t letzteMessung      = 0;
uint32_t letzteDebugAusgabe = 0;

/* ============================================================================
 * FUNKTION: Einen Sensor initialisieren mit eindeutiger I2C-Adresse
 *
 * Ablauf:
 *   1. XSHUT HIGH  -> Sensor wacht auf, antwortet auf Default 0x29
 *   2. begin(neueAdresse) -> Library schreibt neue Adresse ins Sensor-Register
 *   3. Sensor antwortet ab jetzt nur noch auf die neue Adresse
 *
 * Wichtig: Sensoren MÜSSEN nacheinander aktiviert werden (nie parallel).
 * ============================================================================ */
bool sensorAktivieren(Adafruit_VL53L0X &sensor, uint8_t xshutPin,
                      uint8_t neueAdresse, const char* bezeichnung) {
  Serial.print("  -> ");
  Serial.print(bezeichnung);
  Serial.print(" (Adresse 0x");
  Serial.print(neueAdresse, HEX);
  Serial.print(") ... ");

  digitalWrite(xshutPin, HIGH);
  delay(20);  // Boot-Zeit VL53L0X (Datenblatt ~1.2 ms, sicher 20 ms)

  if (!sensor.begin(neueAdresse, false, &Wire)) {
    Serial.println("FEHLER!");
    return false;
  }
  Serial.println("OK");
  return true;
}

/* ============================================================================
 * FUNKTION: Distanz lesen (in cm)
 * ============================================================================ */
uint16_t distanzLesen(Adafruit_VL53L0X &sensor, bool sensorAktiv) {
  if (!sensorAktiv) {
    return DISTANZ_KEIN_ECHO_CM;
  }

  VL53L0X_RangingMeasurementData_t messung;
  sensor.rangingTest(&messung, false);

  // Status 4 = "Out of Range"
  if (messung.RangeStatus == 4) {
    return DISTANZ_KEIN_ECHO_CM;
  }

  uint16_t cm = messung.RangeMilliMeter / 10;
  if (cm > DISTANZ_KEIN_ECHO_CM) {
    cm = DISTANZ_KEIN_ECHO_CM;
  }
  return cm;
}

/* ============================================================================
 * FUNKTION: Frequenz in der NAHEN Zone exponentiell berechnen
 *
 * Eingabe:  distanzCm — irgendwo zwischen zoneKritischCm und zoneNahCm
 * Ausgabe:  Pulsfrequenz in Hz
 *
 * Mathematik:
 *   Wir mappen die Distanz auf einen Faktor t von 0 bis 1:
 *     t = 0  bei der ÄUSSEREN Grenze (zoneNahCm)        -> FREQ_NAH_MIN_HZ
 *     t = 1  bei der INNEREN Grenze (zoneKritischCm)    -> FREQ_NAH_MAX_HZ
 *
 *   Dann skalieren wir die Frequenz exponentiell:
 *     freq = FREQ_NAH_MIN_HZ * (FREQ_NAH_MAX_HZ / FREQ_NAH_MIN_HZ) ^ t
 *
 *   Beispiel mit 4 Hz -> 12 Hz:
 *     bei t=0.0 (25 cm):  4 Hz
 *     bei t=0.5 (17.5 cm): 6.93 Hz
 *     bei t=1.0 (10 cm):  12 Hz
 * ============================================================================ */
float frequenzNaheZoneExp(float distanzCm) {
  // Distanzbereich: nahe Zone geht von zoneNahCm (aussen) nach zoneKritischCm (innen)
  float zonenBreite = (float)(zoneNahCm - zoneKritischCm);
  if (zonenBreite <= 0) return FREQ_NAH_MAX_HZ;  // Sicherheit

  // t = Position innerhalb der Zone (0 = aussen, 1 = innen, je näher desto höher)
  float t = (zoneNahCm - distanzCm) / zonenBreite;

  // Begrenzen auf [0, 1]
  if (t < 0.0f) t = 0.0f;
  if (t > 1.0f) t = 1.0f;

  // Exponentielle Interpolation
  return FREQ_NAH_MIN_HZ * powf(FREQ_NAH_MAX_HZ / FREQ_NAH_MIN_HZ, t);
}

/* ============================================================================
 * FUNKTION: Vibrationsmuster berechnen (Auto-Parksensor + exponentielle Eskalation)
 * ============================================================================ */
uint8_t vibrationBerechnen(float distanzCm, uint32_t jetztMs) {

  // --- Zone "AUS" (>= 100 cm + Offset) ---
  if (distanzCm >= zoneFernCm) {
    return 0;
  }

  // --- Zone "KRITISCH" (<= 10 cm + Offset) — Dauervibration ---
  if (distanzCm <= zoneKritischCm) {
    return STAERKE_KRITISCH;
  }

  // --- Zonen mit Pulsen: Stärke und Frequenz festlegen ---
  uint8_t  staerke;
  float    frequenzHz;

  if (distanzCm <= zoneNahCm) {
    // 10–25 cm: NAHE Zone — exponentielle Frequenz-Eskalation
    staerke    = STAERKE_NAH;
    frequenzHz = frequenzNaheZoneExp(distanzCm);
  }
  else if (distanzCm <= zoneMittelCm) {
    // 25–50 cm: feste mittlere Frequenz
    staerke    = STAERKE_MITTEL;
    frequenzHz = FREQ_MITTEL_HZ;
  }
  else {
    // 50–100 cm: feste langsame Frequenz
    staerke    = STAERKE_FERN;
    frequenzHz = FREQ_FERN_HZ;
  }

  // --- Pulsen erzeugen ---
  // Pulsdauer = 1/Frequenz, Tastverhältnis 50% AN / 50% AUS
  uint32_t pulsdauerMs = (uint32_t)(1000.0f / frequenzHz);
  if (pulsdauerMs == 0) pulsdauerMs = 1;  // Sicherheit gegen Division durch null

  uint32_t phase = jetztMs % pulsdauerMs;

  if (phase < (pulsdauerMs / 2)) {
    return staerke;
  } else {
    return 0;
  }
}

/* ============================================================================
 * FUNKTION: Aktuelle Zone als Text (nur Debug)
 * ============================================================================ */
const char* zoneAlsText(float distanzCm) {
  if (distanzCm >= zoneFernCm)     return "AUS     ";
  if (distanzCm <= zoneKritischCm) return "KRITISCH";
  if (distanzCm <= zoneNahCm)      return "NAH-EXP ";
  if (distanzCm <= zoneMittelCm)   return "MITTEL  ";
  return                                  "FERN    ";
}

/* ============================================================================
 * SETUP
 * ============================================================================ */
void setup() {

  Serial.begin(115200);
  delay(2000);

  Serial.println();
  Serial.println("==========================================");
  Serial.println("  OASIS - Haptisches Navigationssystem");
  Serial.println("  v4.0 - Auto-Profil + Exp.-Eskalation");
  Serial.println("==========================================");

  // --- Effektive Zonen-Grenzen mit Offset berechnen ---
  zoneKritischCm = ZONE_KRITISCH_BASIS_CM + DISTANZ_OFFSET_CM;
  zoneNahCm      = ZONE_NAH_BASIS_CM      + DISTANZ_OFFSET_CM;
  zoneMittelCm   = ZONE_MITTEL_BASIS_CM   + DISTANZ_OFFSET_CM;
  zoneFernCm     = ZONE_FERN_BASIS_CM     + DISTANZ_OFFSET_CM;

  // Sicherheit: Zonen dürfen nicht negativ werden
  if (zoneKritischCm < 1) zoneKritischCm = 1;
  if (zoneNahCm < zoneKritischCm + 1) zoneNahCm = zoneKritischCm + 1;
  if (zoneMittelCm < zoneNahCm + 1)   zoneMittelCm = zoneNahCm + 1;
  if (zoneFernCm < zoneMittelCm + 1)  zoneFernCm = zoneMittelCm + 1;

  // --- 1. Sensoren in Reset ---
  Serial.println("\n[1/4] Sensor-Reset (alle XSHUT auf LOW)");
  pinMode(PIN_XSHUT_VORN,   OUTPUT);
  pinMode(PIN_XSHUT_MITTE,  OUTPUT);
  pinMode(PIN_XSHUT_HINTEN, OUTPUT);
  digitalWrite(PIN_XSHUT_VORN,   LOW);
  digitalWrite(PIN_XSHUT_MITTE,  LOW);
  digitalWrite(PIN_XSHUT_HINTEN, LOW);
  delay(20);

  // --- 2. I2C-Bus starten ---
  Serial.print("[2/4] I2C-Bus starten (SDA=IO");
  Serial.print(PIN_I2C_SDA);
  Serial.print(", SCL=IO");
  Serial.print(PIN_I2C_SCL);
  Serial.println(", 400 kHz)");
  Wire.begin(PIN_I2C_SDA, PIN_I2C_SCL, I2C_BUS_SPEED_HZ);

  // --- 3. Sensoren einzeln aktivieren mit eigenen Adressen ---
  Serial.println("[3/4] Sensoren mit eindeutigen Adressen ausstatten:");
  sensorVornOk   = sensorAktivieren(sensorVorn,   PIN_XSHUT_VORN,
                                    ADRESSE_SENSOR_VORN,   "Sensor VORN  ");
  sensorMitteOk  = sensorAktivieren(sensorMitte,  PIN_XSHUT_MITTE,
                                    ADRESSE_SENSOR_MITTE,  "Sensor MITTE ");
  sensorHintenOk = sensorAktivieren(sensorHinten, PIN_XSHUT_HINTEN,
                                    ADRESSE_SENSOR_HINTEN, "Sensor HINTEN");

  uint8_t anzahl = (sensorVornOk?1:0) + (sensorMitteOk?1:0) + (sensorHintenOk?1:0);
  Serial.print("  -> ");
  Serial.print(anzahl);
  Serial.println(" von 3 Sensoren bereit");

  // --- 4. PWM-Kanäle einrichten ---
  Serial.println("[4/4] PWM-Kanaele fuer Motoren einrichten (20 kHz, 8 Bit)");

  ledcSetup(PWM_KANAL_VORN,   PWM_FREQUENZ_HZ, PWM_AUFLOESUNG);
  ledcSetup(PWM_KANAL_MITTE,  PWM_FREQUENZ_HZ, PWM_AUFLOESUNG);
  ledcSetup(PWM_KANAL_HINTEN, PWM_FREQUENZ_HZ, PWM_AUFLOESUNG);

  ledcAttachPin(PIN_MOTOR_VORN,   PWM_KANAL_VORN);
  ledcAttachPin(PIN_MOTOR_MITTE,  PWM_KANAL_MITTE);
  ledcAttachPin(PIN_MOTOR_HINTEN, PWM_KANAL_HINTEN);

  ledcWrite(PWM_KANAL_VORN,   0);
  ledcWrite(PWM_KANAL_MITTE,  0);
  ledcWrite(PWM_KANAL_HINTEN, 0);

  // --- Zonen-Tabelle ausgeben ---
  Serial.println("\n==========================================");
  Serial.println("  System bereit. Hauptschleife startet.");
  Serial.println("==========================================");
  Serial.print("Distanz-Offset: ");
  Serial.print(DISTANZ_OFFSET_CM);
  Serial.println(" cm");
  Serial.println("\nVibrations-Zonen:");
  Serial.print("  > "); Serial.print(zoneFernCm);     Serial.println(" cm        -> AUS");
  Serial.print("  ");   Serial.print(zoneMittelCm);   Serial.print("-");
  Serial.print(zoneFernCm);     Serial.print(" cm    -> Pulsen ");
  Serial.print(FREQ_FERN_HZ);   Serial.println(" Hz");
  Serial.print("  ");   Serial.print(zoneNahCm);      Serial.print("-");
  Serial.print(zoneMittelCm);   Serial.print(" cm     -> Pulsen ");
  Serial.print(FREQ_MITTEL_HZ); Serial.println(" Hz");
  Serial.print("  ");   Serial.print(zoneKritischCm); Serial.print("-");
  Serial.print(zoneNahCm);      Serial.print(" cm     -> Pulsen ");
  Serial.print(FREQ_NAH_MIN_HZ); Serial.print("->");
  Serial.print(FREQ_NAH_MAX_HZ); Serial.println(" Hz (exp.)");
  Serial.print("  < "); Serial.print(zoneKritischCm); Serial.println(" cm         -> Dauervibration\n");
}

/* ============================================================================
 * LOOP
 * ============================================================================ */
void loop() {
  uint32_t jetzt = millis();

  // --- 1. Distanzen messen ---
  if (jetzt - letzteMessung >= MESSINTERVALL_MS) {
    letzteMessung = jetzt;

    uint16_t rohVorn   = distanzLesen(sensorVorn,   sensorVornOk);
    uint16_t rohMitte  = distanzLesen(sensorMitte,  sensorMitteOk);
    uint16_t rohHinten = distanzLesen(sensorHinten, sensorHintenOk);

    // Tiefpassfilter
    distanzVorn   = (1.0f - FILTER_STAERKE) * distanzVorn   + FILTER_STAERKE * rohVorn;
    distanzMitte  = (1.0f - FILTER_STAERKE) * distanzMitte  + FILTER_STAERKE * rohMitte;
    distanzHinten = (1.0f - FILTER_STAERKE) * distanzHinten + FILTER_STAERKE * rohHinten;
  }

  // --- 2. Vibrationsmuster jeden Loop berechnen (für sauberes Pulsen) ---
  uint8_t pwmVorn   = vibrationBerechnen(distanzVorn,   jetzt);
  uint8_t pwmMitte  = vibrationBerechnen(distanzMitte,  jetzt);
  uint8_t pwmHinten = vibrationBerechnen(distanzHinten, jetzt);

  ledcWrite(PWM_KANAL_VORN,   pwmVorn);
  ledcWrite(PWM_KANAL_MITTE,  pwmMitte);
  ledcWrite(PWM_KANAL_HINTEN, pwmHinten);

  // --- 3. Debug-Ausgabe ---
  if (jetzt - letzteDebugAusgabe >= DEBUG_AUSGABE_MS) {
    letzteDebugAusgabe = jetzt;

    Serial.print("VORN  ");   Serial.print((int)distanzVorn);   Serial.print(" cm [");
    Serial.print(zoneAlsText(distanzVorn));   Serial.print("]  |  ");
    Serial.print("MITTE ");   Serial.print((int)distanzMitte);  Serial.print(" cm [");
    Serial.print(zoneAlsText(distanzMitte));  Serial.print("]  |  ");
    Serial.print("HINTEN ");  Serial.print((int)distanzHinten); Serial.print(" cm [");
    Serial.print(zoneAlsText(distanzHinten)); Serial.println("]");
  }
}
